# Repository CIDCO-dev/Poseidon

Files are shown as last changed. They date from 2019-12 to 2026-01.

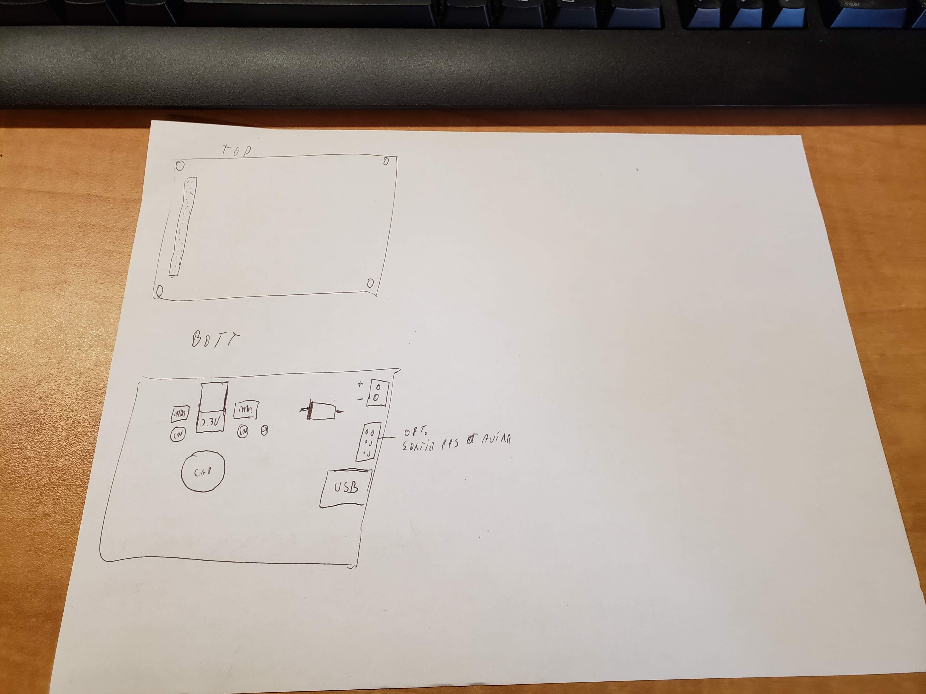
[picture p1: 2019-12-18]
docs/Devices/GPS/Hemisphere P320/20191210_094404.jpg

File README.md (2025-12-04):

# Poseidon
Hydrographic surveying platform operating system (ROS Noetic).

## Getting started (RPi4, Ubuntu 20.04, ROS Noetic)
- Clone under `/opt`: `sudo chown $USER:$USER /opt && cd /opt && git clone --recursive <repo>`
- Install: run `install/rpi4-noetic.sh` (RPi4 target).
- Build: `cd /opt/Poseidon/src/workspace && catkin_make -j1 -DCATKIN_BLACKLIST_PACKAGES="mavros;inertial_sense;velodyne;ins_piksi;velodyne_pointcloud;velodyne_driver;velodyne_laserscan;gnss_mosaic_x5;tf"`
- Source: `source /opt/ros/noetic/setup.bash` then `source /opt/Poseidon/src/workspace/devel/setup.bash`.
- Launch simulator: `roslaunch launch/Simulator/dummy_simulator_virtual-machine.launch`, then open the web UI at `http://localhost`.

## Docs
Full documentation lives in `doc/` (Markdown):
- `doc/README.md`: overview, build, run, tests
- `doc/install.md`: installation with dependencies (RPi4, Ubuntu 20.04, ROS Noetic)
- `doc/nodes.md`: list of ROS nodes
- `doc/web.md`: list of web UI pages
- `doc/web/*.md`: per-page details (index, status, diagnostics, data, map, settings, calibration, goal)
- `doc/nodes/*.md`: per-node details with inputs/outputs/params

## Tests
- C++/Python/ROS: `catkin_make run_tests -j1 -DCATKIN_BLACKLIST_PACKAGES="ins_piksi;libmavconn;echoboat_odometry;mavros_msgs;mavros;mavros_extras;test_mavros;gnss_mosaic_x5;imu_bno055;sonar_imagenex852;inertial_sense;raspberrypi_vitals;imu_null;sonar_dummy;gnss_dummy;lidar_filtering"`
- JS: `cd www/webroot/js && npm test --coverage`

## Tools
- Rosbag replay: `roslaunch launch/Echoboat/rosbag_replay.launch bag_filename:=rosbag.bag`
- Lidar georef: `./devel/lib/logger/lidarGeoreferencer -h` (supports filtering options)
- Logging modes: 1=Always ON, 2=Manual, 3=Speed based

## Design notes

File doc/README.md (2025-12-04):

# Poseidon Documentation

## Overview
- ROS Noetic hydrographic platform.
- Catkin workspace: `src/workspace`.
- Web UI: `www/webroot`.
- Install scripts: `install/stages/`.

## Prerequisites
- Ubuntu 20.04 with ROS Noetic (`/opt/ros/noetic`).
- Build tools: gcc/g++, cmake, ccache, python3, pip, rosdep.
- Node.js 18+ for JS tests (CI uses `actions/setup-node@v4`).

## Installation (RPi4, Ubuntu 20.04, ROS Noetic)
```bash
sudo chown $USER:$USER /opt
cd /opt
git clone --recursive <repo>
sh /opt/Poseidon/install/rpi4-noetic.sh
echo "source /opt/ros/noetic/setup.bash" >> ~/.bashrc
echo "source /opt/Poseidon/src/workspace/devel/setup.bash" >> ~/.bashrc
```

## Build
```bash
cd /opt/Poseidon/src/workspace
catkin_make -j1 -DCATKIN_BLACKLIST_PACKAGES="mavros;inertial_sense;velodyne;ins_piksi;velodyne_pointcloud;velodyne_driver;velodyne_laserscan;gnss_mosaic_x5;tf"
source devel/setup.bash
```

## Run (Simulator)
```bash
roslaunch launch/Simulator/dummy_simulator_virtual-machine.launch
```
Open the web UI at `http://localhost`.

## Tests
- ROS/C++: `catkin_make run_tests -j1 -DCATKIN_BLACKLIST_PACKAGES="ins_piksi;libmavconn;echoboat_odometry;mavros_msgs;mavros;mavros_extras;test_mavros;gnss_mosaic_x5;imu_bno055;sonar_imagenex852;inertial_sense;raspberrypi_vitals;imu_null;sonar_dummy;gnss_dummy;lidar_filtering"`
- JS: `cd www/webroot/js && npm test --coverage`
- Coverage summary: produced in CI (C++/Python/JS).

## Tools & Operations
- Rosbag replay: `roslaunch launch/Echoboat/rosbag_replay.launch bag_filename:=rosbag.bag`
- Lidar georef: `./devel/lib/logger/lidarGeoreferencer -h` (supports filtering with `-f -a -b -d -e`)
- Logging modes: 1=Always ON, 2=Manual, 3=Speed based

## Structure
- `src/workspace/src/<package>`: ROS packages
- `src/workspace/launch/`: launch files
- `www/webroot`: web UI assets and JS
- `install/stages`: install scripts
- `config.txt`: runtime config (no real secrets)
- Docs index: [`doc/nodes.md`](nodes.md) for ROS nodes, [`doc/web.md`](web.md) for web pages

## Notes
- Keep docs up to date here; CI can generate PDFs later if needed.
- For embedded targets, adjust blacklist/launch files for resources.

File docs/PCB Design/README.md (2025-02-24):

# Poseidon-PCB
PCBs for Poseidon Project

PCBs are design with Kicad 8.0

HB-HAT
HydroB HAT interface between RPI and devices

HB-BP
Power module bypass for Hydroblock

HB-PM
Power module for Hydroball

HB-HL
Led and hall interface module for Hydroball

HB-LED
Led PCB

HB-PM-Prog
Power Module Programmation Interface

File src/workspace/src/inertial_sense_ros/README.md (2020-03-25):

# inertial_sense

A ROS wrapper for the InertialSense uINS3 RTK-GPS-INS and Dual GPS (GPS Compassing) sensor.

## NOTICE:

To use this node, the uINS should be updated with the latest firmware found on the Inertial Sense [release page](https://github.com/inertialsense/InertialSenseSDK/releases). Download the appropriate `.hex` file and use the `firmware_update` ROS service to update the firmware
``` 
rosservice call /firmware_update ~/Download/IS_uINS-3_<...>.hex
```

## Installation
This ROS package, uses the InertialSenseSDK as a submodule. Clone this package into the catkin workspace `src` folder, then pull the submodule.

``` bash
mkdir -p catkin_ws/src
cd catkin_ws/src
catkin_init_workspace
git clone https://github.com/inertialsense/inertial_sense_ros
cd inertial_sense_ros
git submodule update --init --recursive
cd ../..
catkin_make
```

## Running the Node

```bash
rosrun inertial_sense inertial_sense_node
```

The user must be a member of the `dailout` group, or the user won't have access to the serial port.

For instructions on changing parameter values and topic remapping from the command line while using `rosrun` refer to the [Remapping Arguments](http://wiki.ros.org/Remapping%20Arguments) page. To set vector parameters, use the following syntax:

``` bash
rosparam set /inertial_sense_node/GPS_ref_lla "[40.25, -111.67, 1556.59]"
rosrun inertial_sense inertial_sense_node
```

To set parameters and topic remappings from a launch file, refer to the [Roslaunch for Larger Projects](http://wiki.ros.org/roslaunch/Tutorials/Roslaunch%20tips%20for%20larger%20projects) page, or the sample `launch/test.launch` file in this repository.

## Time Stamps

If GPS is available, all header timestamps are calculated with respect to the GPS clock but are translated into UNIX time to be consistent with the other topics in a ROS network.  If GPS is unvailable, then a constant offset between uINS time and system time is estimated during operation  and is applied to IMU and INS message timestamps as they arrive.  There is often a small drift in these timestamps (on the order of a microsecond per second), due to variance in measurement streams and difference between uINS and system clocks, however this is more accurate than stamping the measurements with ROS time as they arrive.  

In an ideal setting, there should be no jump in timestamps when GPS is first acquired, because the timestamps should be identical, however, due to inaccuracies in system time, there will likely be a small jump in message timestamps after the first GPS fix.

## Topics

Topics are enabled and disabled using parameters.  By default, only the `ins` topic is published to save processor time in serializing unecessary messages.
- `ins`(nav_msgs/Odometry)
    - full 12-DOF measurements from onboard estimator (pose portion is from inertial to body, twist portion is in body frame)
- `imu`(sensor_msgs/Imu)
    - Raw Imu measurements from IMU1 (NED frame)
- `gps`(inertial_sense/GPS)
    - unfiltered GPS measurements from onboard GPS unit
- `gps/info`(inertial_sense/GPSInfo)
    - sattelite information and carrier noise ratio array for each sattelite
- `mag` (sensor_msgs/MagneticField)
    - Raw magnetic field measurement from magnetometer 1
- `baro` (sensor_msgs/FluidPressure)
    - Raw barometer measurements in kPa
- `preint_imu` (inertial_sense/DThetaVel)
    - preintegrated coning and sculling integrals of IMU measurements
- `RTK/info` (inertial_sense/RTKInfo)
    - information about RTK status
- `RTK/rel` (inertial_sense/RTKRel)
    * Relative measurement between RTK base and rover
- `gps/obs` (inertial_sense/GNSSObservation)
    * Raw satellite observation (psuedorange and carrier phase)
- `gps/eph` (inertial_sense/GNSSEphemeris)
    * Satellite Ephemeris for GPS and Galileo GNSS constellations
- `gps/geph`
    * Satellite Ephemeris for Glonass GNSS constellation

## Parameters

* `~port` (string, default: "/dev/ttyUSB0")
  - Serial port to connect to
* `~baudrate` (int, default: 921600)
  - baudrate of serial communication
* `~frame_id` (string, default "body")
  - frame id of all measurements
* `~LTCF` (int, default: 0)
  - Local Tangent Coordinate Frame: 0 - NED, 1 - ENU

**Topic Configuration**
* `~navigation_dt_ms` (int, default: Value retrieved from device flash configuration)
   - milliseconds between internal navigation filter updates (min=2ms/500Hz).  This is also determines the rate at which the topics are published.
* `~stream_INS` (bool, default: true)
   - Flag to stream navigation solution or not
* `~stream_IMU` (bool, default: false)
   - Flag to stream IMU measurements or not
* `~stream_baro` (bool, default: false)
   - Flag to stream baro or not
* `~stream_mag` (bool, default: false)
   - Flag to stream magnetometer or not
* `~stream_preint_IMU` (bool, default: false)
   - Flag to stream preintegrated IMU or not
* `~stream_GPS`(bool, default: false)
   - Flag to stream GPS
* `~stream_GPS_info`(bool, default: false)
   - Flag to stream GPS info messages
- `~stream_GPS_raw` (bool, default: false)
   - Flag to stream GPS raw messages
- `~publishTf`(bool, default: true)
   - Flag to publish Tf transformations 'ins' to 'body_link'

**RTK Configuration**
* `~RTK_rover` (bool, default: false)
  - Enables RTK rover mode (requires base corrections from an RTK base)
* `~RTK_base` (bool, default: false)
  - Makes the connected uINS a RTK base station and enables the publishing of corrections
* `~dual_GNSS` (bool, default: false)
  - Uses both GPS antennas in a dual-GNSS configuration
* `~RTK_server_IP` (string, default: 127.0.0.1)
  - If operating as base, attempts to create a TCP port on this IP for base corrections, if rover, connects to this IP for corrections.
* `~RTK_server_port` (int, default: 7777)
  - If operating as base, creates a TCP connection at this port for base corrections, if rover, connects to this port for corrections.
* `~RTK_correction_type` (string, default: UBLOX)
  - If operating with limited bandwidth, choose RTCM3 for a lower bandwidth, but less accurate base corrections,  rover and base must match

**Sensor Configuration**
* `~INS_rpy_radians` (vector(3), default: {0, 0, 0})
    - The roll, pitch, yaw rotation from the INS frame to the output frame
* `~INS_xyz` (vector(3), default: {0, 0, 0})
    - The NED translation vector between the INS frame and the output frame (wrt output frame)
* `~GPS_ant1_xyz` (vector(3), default: {0, 0, 0})
    - The NED translation vector between the INS frame and the GPS 1 antenna (wrt INS frame)
* `~GPS_ant2_xyz` (vector(3), default: {0, 0, 0})
    - The NED translation vector between the INS frame and the GPS 2 antenna (wrt INS frame)
* `~GPS_ref_lla` (vector(3), default: {0, 0, 0})
    - The Reference longitude, latitude and altitude for NED calculation in degrees, degrees and meters (use the `set_refLLA` service to update this automatically)
* `~inclination` (float, default: 1.14878541071)
    - The inclination of earth's magnetic field (radians)
* `~declination` (float, default: 0.20007290992)
    - The declination of earth's magnetic field (radians)
* `~dynamic_model` (int, default: 8)
    - Dynamic model used in internal filter of uINS.
       - 0 = portable
       - 2 = stationary
       - 3 = pedestrian
       - 4 = automotive
       - 5 = sea
       - 6 = airborne 1G
       - 7 = airborne 2G
       - 8 = airborne 4G
       - 9 = wrist

**ASCII Output Configuration**
* `~ser1_baud_rate` (int, default: 921600)
    - baud rate for serial1 port used for external NMEA messaging (located on H6-5) [serial port hardware connections](http://docs.inertialsense.com/user-manual/Setup_Integration/hardware_integration/#pin-definition)
* `~NMEA_rate` (int, default: 0)
    - Rate to publish NMEA messages
* `~NMEA_configuration` (int, default: 0x00)
    - bitmask to enable NMEA messages (bitwise OR to enable multiple message streams).
      - GPGGA = 0x01
      - GPGLL = 0x02
      - GPGSA = 0x04
      - GPRMC = 0x08
* `~NMEA_ports` (int, default: 0x00)
    - bitmask to enable NMEA message on serial ports (bitwise OR to enable both ports) 
      - Ser0 (USB/H4-4)  = 0x01 
      - Ser1 (H6-5) = 0x02 

## Services
- `single_axis_mag_cal` (std_srvs/Trigger)
  - Put INS into single axis magnetometer calibration mode.  This is typically used if the uINS is rigidly mounted to a heavy vehicle that will not undergo large roll or pitch motions, such as a car. After this call, the uINS must perform a single orbit around one axis (i.g. drive in a circle) to calibrate the magnetometer [more info](http://docs.inertialsense.com/user-manual/Setup_Integration/magnetometer_calibration/)
- `multi_axis_mag_cal` (std_srvs/Trigger)
  - Put INS into multi axis magnetometer calibration mode.  This is typically used if the uINS is not mounted to a vehicle, or a lightweight vehicle such as a drone.  Simply rotate the uINS around all axes until the light on the uINS turns blue [more info](http://docs.inertialsense.com/user-manual/Setup_Integration/magnetometer_calibration/)
- `firmware_update` (inertial_sense/FirmwareUpdate)
  - Updates firmware to the `.hex` file supplied (use absolute filenames)
* `set_refLLA_current` (std_srvs/Trigger)
  - Takes the current estimated position and sets it as the `refLLA`.  Use this to set a base position after a survey, or to zero out the `ins` topic.1
* `set_refLLA_value` (std_srvs/Trigger)
  - Sets `refLLA` to the values passed as service arguments of type float64[3].  Use this to set refLLA to a known value.

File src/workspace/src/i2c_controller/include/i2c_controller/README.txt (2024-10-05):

action to perform :
led_error
led_ready
led_recording
led_warning
led_nofix
get_led_state
gps_fix_ready
gps_fix_recording
get_humidity
get_temperature
get_voltage
get_shuntVoltage
get_batteryTemperature

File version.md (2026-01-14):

# Version History (English)

## 2026-01-12
- CI: clean Catkin build/devel/logs on self-hosted runners before builds to avoid `.built_by` permission errors.
- CI: pre-clean the GitHub Actions workspace with sudo before checkout to avoid permission errors during repository cleanup.

## 2026-01-08
- e2e: require root launch by default (`POSEIDON_E2E_LAUNCH_AS_ROOT=1`) and reuse the already-started service during the E2E run to avoid duplicate roslaunch.
- diagnostics/e2e: honor `POSEIDON_E2E_LAUNCH_AS_ROOT=1` when the websocket integration test launches `launchROSService.sh`.
- e2e: split the E2E runner into explicit phases (start ROS + wait for nodes, backend test, UI test) with optional required node gating (`POSEIDON_E2E_REQUIRED_NODES`).
- CI: set `POSEIDON_E2E_LAUNCH_AS_ROOT=1` for hardware E2E runs to ensure sensor access.

## 2025-12-18
- e2e: added Playwright-based headless UI smoke test (verifies `diagnostics.html` populates diagnostics + running nodes tables and required sensor diagnostics report OK; optional telemetry check on `index.html`).
- e2e: added unified runner script that starts Poseidon, serves `www/webroot`, waits for ports, runs backend websocket E2E + UI headless checks, and stores artifacts under `test/e2e/artifacts`.
- diagnostics/e2e: gated the launchROSService websocket test behind `POSEIDON_E2E=1` and added `POSEIDON_E2E_REUSE_RUNNING=1` to support CI benches that already run ROS.
- diagnostics: start the WebSocket server from inside the asyncio loop to be compatible with newer `websockets` versions (fixes port 9099 not opening on some systems).
- launch: made `launchROSService.sh` relocatable via `POSEIDON_ROOT` (no longer hard-coded to `/opt/Poseidon`).
- launch: avoid `set -u` in `launchROSService.sh` so sourcing `/opt/ros/noetic/setup.bash` does not fail when ROS scripts reference unset variables (fixes CI E2E startup).
- launch/e2e: pass `loggerPath` and `configPath` from `POSEIDON_LOGGER_PATH` / `POSEIDON_CONFIG_PATH` via `launchROSService.sh` (avoids invalid nested `$(optenv ...)` substitutions in roslaunch args).
- CI: added optional "hardware E2E" workflow steps (Playwright install, run E2E, upload artifacts) triggered on `workflow_dispatch` or pushes to `main/master`.
- diagnostics/e2e: make IMU/sonar communication thresholds configurable via env vars (`POSEIDON_DIAG_IMU_*`, `POSEIDON_DIAG_SONAR_*`) to reduce false negatives on slower benches.
- e2e: allow tuning diagnostics refresh polling delay via `POSEIDON_E2E_DIAGNOSTICS_REFRESH_DELAY_MS` for longer-running diagnostics windows.
- e2e: on UI failure, runner now dumps `roslaunch` tail + basic `rostopic`/diagnostics websocket debug into the job logs for faster triage.
- e2e: avoid `set -u` in the E2E runner when sourcing ROS setup scripts (prevents `ROS_DISTRO: unbound variable` on some environments).
- e2e: keep a DBT NMEA writer running for the whole E2E so `/depth` can be validated when `DIAGNOSTICS_FAKE_SERIAL_PORT` is available.
- e2e: optional exclusive mode (`POSEIDON_E2E_EXCLUSIVE=1`) stops the system `ros` service and frees websocket ports before starting Poseidon to avoid port conflicts on benches.
- launch: pass `sonarDevice` into the Hydrobox launch and map it to `/Sonar/device` so the sonar node can be pointed at a test serial adapter.

## 2025-12-03
- diagnostics: added end-to-end nosetest that launches `launchROSService.sh`, waits for the 9099 diagnostics websocket, sends `updateDiagnostic`, and validates the returned payload; optional DBT feed on `DIAGNOSTICS_FAKE_SERIAL_PORT` (default `/dev/ttyUSB1`) to drive sonar without touching `/dev/sonar`.
- diagnostics: declare `python3-websockets` as exec/test dependency so websocket clients/servers are available during integration runs.
- diagnostics: fixed indentation in the launchROSService websocket test teardown to avoid SyntaxErrors during nosetests.
- diagnostics: guarded `asyncio.set_event_loop` in `diagnostics_websocket.start_server` to prevent dummy-loop `AssertionError` in unit tests.

## 2025-12-02
- Web UI: System Status now shows wlan0 state + SSID using sysfs/proc+iwgetid (no nmcli dependency in telemetry path).
- hydroball_data_websocket: publish Wi‑Fi status/SSID in telemetry payload (`telemetry.wifi`), sourced from `/sys/class/net/wlan0/operstate` and `/proc/net/wireless`.
- wifi_file_transfer_config: remove legacy C++ backups; node now purges old Wi‑Fi connections on config change and documentation/comments converted to English.
- wifi_file_transfer_config: added Python unit tests for wifi_config_node (helpers, nmconnection parsing, autoconnect parsing, purge logic, configuration callback) wired via catkin nosetests.
- Launch: replace missing `diagnostics_node` with `diagnostics_websocket.py` in Hydrobox/Hydroball/Simulator launch files to fix diagnostics startup errors.
- diagnostics: add package-path fallback so diagnostics_websocket imports sibling diagnostic modules when run from install space (fix ModuleNotFoundError on diagnostics_test_base).
- diagnostics: fix `getRunningNodes` handler to unpack publisher/subscriber/service lists correctly (no more "too many values to unpack").
- diagnostics: add DNS resolution check (`google.com`) and Internet connectivity check (`http://example.com`) to the diagnostics suite.
- diagnostics: run Internet connectivity first and skip DNS/API checks when connectivity fails to reduce noisy errors.
- diagnostics: API connection test now uses a configurable timeout (default 2s) to avoid hanging when the API domain is blocked.
- diagnostics: added unit tests for the diagnostics websocket node (commands, node listing, lifecycle helpers) to cover its behaviors without ROS master dependencies.
- diagnostics: install the websocket integration test into the package bin path and skip cleanly when the `websockets` module is missing, so rostest can locate/execute it without false negatives.
- install: rewrote `install/stages/ethernet_move_hotspot_rpi4.sh` with Unix line endings so the bash shebang runs without `/bin/bash^M` errors.
- install: fixed `ethernet_move_hotspot_rpi4.sh` variable handling (no more escaped `$`/awk errors) and robust interface-name replacement in Hotspot.nmconnection.
- launch: All Hydrobox profiles now start `wifi_file_transfer_config_node` so Wi‑Fi provisioning is consistent across RPi/Rock and simulator setups.
- launch: Fixed wifi file transfer node type to `wifi_config_node.py` in all launch profiles/simulator so roslaunch can locate the installed Python node.
- wifi_file_transfer_config: protect hotspot/non-target interfaces (e.g., wlan1) and force new connections onto `wlan0`; skip deleting hotspot profiles when applying Wi‑Fi config.
- wifi_file_transfer_config: refuse to apply Wi‑Fi changes if the hotspot interface (default wlan1) is missing and guard against running when the target interface is absent.
- hydroball_data_websocket: use nmcli to populate Wi‑Fi SSID/state, drop iwgetid dependency, and clear SSID when disconnected.
- Web UI (status): Wi‑Fi row matches other bars (full-width gradient green/red) with SSID + state inline in the header; bar color now follows `wifi.state` up/down.
- Tests: update statusScript Jest stubs to support `.css()` chaining after Wi‑Fi bar changes.

## 2025-12-01
- diagnostics: added rostest that launches the WebSocket node and validates `updateDiagnostic` response payload (catkin test friendly).
- raspberrypi_vitals: declare logger_service and power_management_msg dependencies so ToggleLogging and battery message headers exist at build time.
- diagnostics: install the websocket integration test script via catkin so rostest can locate/execute it.
- ROS tests: add pytest skip guards for ROS-dependent Python tests to avoid failures when ROS Python modules are absent.

## 2025-11-27
- CI: gcovr step split into separate XML/HTML runs (no more skipped HTML output) and coverage summary script now falls back to lcov/HTML when XML is absent.
- CI: coverage summary now also falls back to JS lcov when coverage-summary.json is missing (ensures JS coverage is reported).
- CI: coverage summary surfaces JUnit test totals/errors/failures and lists failing suites (links to junit-test-results artifact).
- JS: VM-based Jest tests now instrument scripts before execution so coverage is reported correctly (no longer 0%).
- raspberrypi_vitals: ensure targets depend on generated messages (catkin_EXPORTED_TARGETS) and declare i2c_controller_service in CATKIN_DEPENDS to fix missing `raspberrypi_vitals_msg/sysinfo.h` during build.
- gnss_zed_f9p: declare binary_stream_msg/virtual_serial_port deps and depend on catkin_EXPORTED_TARGETS so generated headers (e.g., Stream.h) exist before building.
- lidar_filtering: fixed tests by passing min/max angle/distance as const refs in Filters helpers (no more rvalue binding errors).
- CI: junit summary lines are now highlighted in red when errors/failures/skipped are non-zero for easier scanning.
- Docs: agent guidance updated to keep Markdown docs in `doc/` (source of truth) with CI able to generate PDFs for download.
- Docs: README and doc/README now target RPi4 on Ubuntu 20.04, using install/rpi4-noetic.sh as the install path.
- Docs: added `doc/install.md` detailing prerequisites and install steps for RPi4 Ubuntu 20.04.
- Docs: added `doc/nodes.md` (ROS nodes list) and `doc/web.md` (web UI pages list); README links updated.
- Docs: added per-web-page stubs in `doc/web/*.md` (index, status, diagnostics, data, map, settings, calibration, goal).
- Docs: node/web index now link to specific Markdown docs and source files for easier navigation.
- Docs: documented `sonar_dummy_node` (overview, published topic, config service keys, behavior).
- Docs: documented `raspberrypi_vitals_node` (vitals topic fields, I2C service calls, thresholds).
- Docs: documented `imu_null_node` (zeroed IMU publisher at 200 Hz).
- Docs: documented `hydroball_config_websocket_node` (websocket config server, services, config file handling, IMU transform broadcast).
- Docs: documented `logger_binary_node` (binary logging of GNSS/IMU/sonar/lidar/vitals/speed, rotation/transfer).
- Docs: documented `logger_text_node` (per-stream text logs, rotation/transfer).
- Docs: documented `gnss_dummy_node` (synthetic NavSatFix publisher with alternating status/path).
- Docs: documented `gnss_zed_f9p_node` (serial UBX ingest, speed/diag/raw stream).
- Docs: documented `video_recorder_node` (camera capture → EXIF-tagged PNGs with interpolated GNSS).
- Docs: documented `hydroball_data_websocket_node` (WebSocket telemetry/recording control on port 9002).
- Docs: documented `state_controller_node` (aggregates fix/IMU/depth/vitals into state + get_state service).
- Docs: documented `sonar_nmea_0183_tcp_client` (network + serial NMEA readers publishing depth/fix/speed).
- Docs: documented `diagnostics_websocket_node` (WebSocket diagnostics/ running-nodes commands on port 9099).
- Docs: documented `imu_dummy_node` (synthetic IMU on imu/data at 200 Hz).
- Docs: documented `gnss_mosaic_x5_node` (raw SBF logger; waits for fix, reads serial, writes .sbf).
- Docs: documented `lidar_filtering_node` (angle/distance pointcloud filter).
- Docs: documented `hydroball_files_websocket_node` (WebSocket file listing/deletion/transfer control on port 9003).

# 2025-12-02
- Diagnostics: added unit tests for the diagnostics websocket node (commands, node listing, lifecycle helpers) to cover its behaviors without ROS master dependencies.

## 2025-11-27

## 2025-11-26
- Install scripts: added shared chrony update script (PPS/NMEA + pool.ntp.org); lighttpd now points to `/opt/Poseidon/www/webroot`.
- Logger: removed warning spam when toggle requested without GPS fix (ROS1).
- CI: GitHub Actions now posts C++/Python/JS coverage summary to the workflow summary.
- Logger: transfer loop now counts zip files once, reports status, sends, and removes on success; RapidJSON string creation simplified.
- CI: Fixed YAML indentation for coverage summary step (workflow now parses correctly).
- CI: Coverage summary heredoc anchored with indentation (python block).
- CI: Coverage summary heredoc flattened (no leading spaces) to avoid Python IndentationError.
- CI: Coverage summary now runs from a separate script `.github/workflows/scripts/coverage_summary.py`.
- Build fix: added `binary_stream_msg` dependency to diagnostics package (resolves missing `binary_stream_msg/Stream.h` include).

## 2025-11-25
- Added HTTPS transfer integration tests for logger binary and text nodes (local TLS server, payload verification).
- Added memory-resilience tests: repeated failed transfers must not increase RSS.
- Fixed `create_json_str` to avoid allocation leak (use `SetString` without manual `new`).
- Updated agent guidelines to maintain this `version.md`.
- Updated agent guidelines: C++ formatting/lint (`clang-format`, `clang-tidy`) now tracked in the Review & PR checklist.
- Updated agent guidelines: Python formatting (`black`) added to the Review & PR checklist.
- CI: JavaScript tests step now targets `www/webroot/js` (npm ci/install + npm test if package.json present).
- Added Jest setup in `www/webroot/js` with a syntax smoke test for all JS files.
- Added Jest tests for dashboardscript.js and script.js (basic DOM/jQuery stubs, helper behavior checks).
- Added Jest test stub for poseidon.js (verifies WebSocketInit is defined).
- Added Jest tests for statusScript.js (processState handling of uptime/humidity and missing telemetry).
- Added Jest tests for settingsScript.js (rendering config and saveConfig payload).
- Added Jest tests for recordingScript.js and mapScript.js (stubs for WebSocket/Leaflet; basic behavior checks).
- Added Jest tests for diagnosticsScript.js (table population for diagnostics and running nodes).
- Added Jest tests for dataScript.js (state processing, publish status UI updates).
- Added Jest test for calibrationScript.js (zeroImu command dispatch).
- JavaScript: npm test now runs Jest with coverage (collects coverage excluding minified/vendor).
- Fixed logger text test build by defining `currentRssBytes` helper in `test_logger_text_node.cpp`.
- CI: add C++ coverage via gcovr, Python coverage via coverage/pytest, JS coverage artifact upload; switched C++ build to `--coverage`.
- CI: install Node 18 with setup-node to satisfy Jest engine requirements for JS tests.
- JS: add guards/stubs for WebSocket/jQuery/Leaflet in browser scripts to allow Jest to run headless, and exclude node_modules/coverage from syntax scan.
- JS: added Jest jsdom setup with global stubs (window/document/$/WebSocket), guarded polling, and map/WKT fallbacks to stabilize headless tests and avoid npm ci lockfile errors.
- JS tests: added explicit `jest-environment-jsdom` devDependency to satisfy Jest config.
- JS housekeeping: generated package-lock for reproducible installs and removed committed coverage output; keep coverage artifacts untracked.
- hydroball_config_websocket: add message deps (geometry/state/setting) to catkin/package.xml and enforce build order on message targets to fix missing Setting.h during catkin_make.
- Logger tests: removed embedded PEM key/cert; tests now generate ephemeral self-signed TLS material at runtime to avoid shipping secrets.
- sonar_nmea_0183_tcp_client: use ROS params for IP/port (instead of argv) and add socket receive timeout to reconnect if the network stream stalls.
- Install scripts: added shared chrony update script (PPS/NMEA + pool.ntp.org); lighttpd now points to `/opt/Poseidon/www/webroot`.

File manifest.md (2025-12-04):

# Poseidon — Project Manifest

This document summarizes Poseidon: goals, architecture, dependencies, install/build/run procedures, key launch profiles, and core ROS nodes and topics.

## Overview
- Platform: ROS Noetic (Ubuntu 20.04), Catkin workspace.
- Purpose: Embedded OS for hydrographic surveying (GNSS, IMU, sonar, lidar, power management, logging, on‑device web UI).
- License: MIT (see `LICENSE`).

## Top‑Level Layout
- `src/workspace`: Catkin workspace
  - `src`: ROS packages (C++/Python): `logger`, `gnss_zed_f9p`, `imu_bno055`, `sonar_*`, `state_controller`, `hydroball_*_websocket`, `power_*`, etc.
  - `launch`: `roslaunch` files (Echoboat, Hydrobox, Hydroball, Simulator, Cartographer, Rosbag, Binairy)
  - `config`: workspace‑specific config
- `install`: install/provision scripts (stages for x64, RPi, RockPi)
- `tools`: utilities (rosbag editing, lidar georeferencing, GNSS config, I2C tools)
- `www/webroot`: static web UI (dashboard, data, settings, map)
- `service`: system scripts (e.g., `uart_on_boot.sh`)
- `georef`: Python library for geodesy/ENU + tests
- `README.md`: install/build/run (VM and simulation)
- `Jenkinsfile`: CI pipeline (unit tests on ROS VM)

## Launch Entry Points
- WebSockets only: `roslaunch launch/websocket.launch`
- VM simulator: `roslaunch launch/Simulator/dummy_simulator_virtual-machine.launch`
- Echoboat (example): `roslaunch launch/Echoboat/echoboat.launch`
- Hydrobox (RPi, NMEA sonar + ZED‑F9P + BNO055): `roslaunch launch/Hydrobox/hydrobox_rpi_nmeadevice_ZED-F9P_bno055.launch`
- GNSS helpers: scripts `bin_mosaic-x5.sh`, `bin_piksi.sh`

`launchROSService.sh` centralizes common launch profiles and is used by the systemd `ros` service.

## Configurations & Features

### Common Features
- GNSS via gpsd + vendor node: publishes `fix`, `speed`, `gnss_status`, optional binary stream; `.ubx` logging supported.
- IMU BNO055 (I2C) with calibration: publishes `/imu/data`, `/imu/raw`, `/imu/mag`, `/imu/temp`.
- Sonar depth acquisition (NMEA 0183 device or Imagenex 852): publishes `depth` (and `depth_enu` where applicable).
- I2C board and LED/status handling: `i2c_controller`.
- System vitals: `raspberrypi_vitals` (CPU temp/load, RAM/HDD, uptime, battery voltage).
- State aggregation: `state_controller` combines GNSS/IMU/sonar/vitals into `state`.
- Logging: `logger_text_node` with file rotation, modes (Always/Manual/Speed), geofence and optional API transfer.
- WebSockets/UI: `hydroball_config_websocket`, `hydroball_data_websocket`, `hydroball_files_websocket`.
- Diagnostics: `diagnostics` WebSocket diagnostics and communication checks.
- Shared launch args: `loggerPath`, `configPath`, `gpsdIp`, `gpsdPort`.

### Hydrobox‑Specific
- Multiple hardware and GNSS variants: RPi and Rock profiles; GNSS receivers include Piksi and Mosaic X5 in addition to ZED‑F9P (see `launch/Hydrobox/*`).
- Optional “IMU null” profiles (no IMU).
- Imagenex 852 Python driver variant in some profiles (no trigger control).
- Optional rosbag record of all topics in certain profiles.

### Hydroball‑Specific
- Power control and safe shutdown: `power_control` for rails, `power_management` triggers graceful shutdown on low voltage.
- Imagenex 852 C++ driver with trigger control: `trigger_mode` (auto|manual), `manual_ping_rate`, `data_points`.
- Alternate sonar ISA500 via NMEA device (`nmea_device_node`).
- Explicit sonar datagram extension `.img852` configured in logger params.

## Build
Prereqs (excerpt):
- ROS Noetic, catkin, g++, python3-rosdep, ros-noetic-tf2-geometry-msgs, ros-noetic-mavros, ros-noetic-sbg-driver
- Tools: `python3-wstool`, `python3-rosinstall`, `build-essential`, `ninja-build` (for Cartographer), `gpsd` and `gpsd-clients` (x64)

Steps (VM, per `README.md`):
1) Clone into `/opt`: `/opt/Poseidon`
2) Run install scripts for your target, e.g.: `install/stages/1-base-ros-noetic.sh`, `2-x64.sh`, `3-network.sh`, `4-x64.sh`, `5-finalize.sh`
3) Source ROS: `source /opt/ros/noetic/setup.bash`
4) Build workspace: `cd src/workspace && catkin_make -j1 -DCATKIN_BLACKLIST_PACKAGES="mavros;...;inertial_sense;lidar_filtering"`
5) Source workspace: `source devel/setup.bash`

Notes:
- The workspace toplevel `CMakeLists.txt` is a symlink to Catkin’s `toplevel.cmake`.
- Embedded targets may use a blacklist to reduce footprint.

## Run
- Simulator: `roslaunch launch/Simulator/dummy_simulator_virtual-machine.launch`
- Production: choose a profile under `launch/Hydrobox/*` or `launch/Echoboat/*`, or enable the systemd `ros` service (see `install/stages/4-x64.sh`).
- Web UI: served from `www/webroot` (see VM network scripts). Open `http://localhost`.

## Application Configuration
- File: `config.txt` at repo root. Common keys:
  - `apiKey`, `apiServer`, `apiPort`, `apiUrlPath`
  - `geofence` (WKT), sensor offsets (`headingOffset`, `pitchOffset`, `rollOffset`)
  - Sonar: `sonarAbsorbtion`, `sonarPulseLength`, `sonarRange`, `sonarSerialBaudRate`, `sonarStartGain`
  - Logging: `logRotationIntervalSeconds`, `loggingMode` (1=Always ON, 2=Manual, 3=Speed based)
  - Network: `wifiSSID`, `wifiPassword`, `wifiTransferEnabled`

Launch files commonly pass `configPath` and `loggerPath` to WebSocket/logger nodes.

## System Service (systemd)
- Service `ros` created by `install/stages/4-x64.sh` with `ExecStart=/opt/Poseidon/launchROSService.sh`.
- Dependencies: `gpsd.service`, `hwrtc.service` (if present)
- Control: `sudo systemctl enable|start|stop ros`

## Tests and CI
- Unit tests: `catkin_make run_tests -j1` (see README blacklist examples).
- Jenkins: `Jenkinsfile` runs `scripts/vm_tests` and collects `build/test_results/angles/gtest-utest.xml`.

## Useful Scripts (examples)
- Rosbag record/replay: `tools/ROSBag-Eample/*.sh`, `launch/Rosbag/*`
- Lidar georeferencing: `tools/Georef_script/*.bash`, `logger/lidarGeoreferencer` (after build)
- Rosbag editing (python/C++): `tools/Edit-Rosbag/*`
- GNSS ZED‑F9P config/validate: `tools/GNSS-Config-Files/ZED-F9P/*`
- I2C/Diagnostics: `tools/i2c/*`, package `diagnostics`

## Web UI
- Static assets in `www/webroot` (SB Admin 2, MIT): `index.html`, `status.html`, `settings.html`, `map.html`, etc.
- WebSocket nodes (`hydroball_*_websocket`) expose configuration, data and files to the UI.
- Status page now surfaces Wi‑Fi state/SSID (wlan0) from telemetry.

## Network and Ports (common)
- Internal API: `apiPort` (8080 default in `config.txt`).
- GPSD: 2947 (default), passed via launch args.
- Web: local HTTP server; Wi‑Fi file transfer via dedicated scripts/services.

## Data and Logs
- Default recording folder: `/opt/Poseidon/www/webroot/record/` (see `loggerPath` launch arg).
- GNSS binary datagrams may use `.ubx` (see `/logger/fileExtensionForGpsDatagram`).

## Nodes and Topics
Core nodes used by main launch profiles, with their primary ROS interfaces.

- i2c_controller_node (package `i2c_controller`)
  - Publishes: `led_control` (std_msgs/String)
  - Services (server): `i2c_controller_service` (i2c_controller_service/i2c_controller_service)
  - Services (client): `get_logging_status` (logger_service)
  - Args: `boardVersion` (e.g., 2.2)

- power_management_node (package `power_management`)
  - Services (client): `i2c_controller_service` → action `get_voltage`
  - Behavior: triggers graceful shutdown via systemd if voltage is critical

- raspberrypi_vitals_node (package `raspberrypi_vitals`)
  - Publishes: `vitals` (raspberrypi_vitals_msg/sysinfo)

- hydroball_config_websocket_node (package `hydroball_config_websocket`)
  - Publishes: `configuration` (setting_msg/Setting)
  - Services (server): `get_configuration` (setting_msg/ConfigurationService), `zero_imu_offsets` (setting_msg/ImuOffsetService)
  - Args: `configPath` to `config.txt`

- gpsd_client (package `gps_umd`)
  - Publishes: `fix` (sensor_msgs/NavSatFix)
  - Args: `gpsdIp`, `gpsdPort`

- gnss_zed_f9p_node (package `gnss_zed_f9p`)
  - Subscribes: `fix` (sensor_msgs/NavSatFix)
  - Publishes: `speed` (nav_msgs/Odometry), `gnss_bin_stream` (binary_stream_msg/Stream), `gnss_status` (gnss_status_msg/GnssDiagnostic)
  - Args: `loggerPath` (output folder), `gnssPortPath` (serial device)

- gnss_mosaic_x5_node (package `gnss_mosaic_x5`)
  - Subscribes: `fix` (sensor_msgs/NavSatFix)

- sonar_nmea_0183_tcp_client (package `sonar_nmea_0183_tcp_client`)
  - Publishes: `depth` (geometry_msgs/PointStamped), `fix` (sensor_msgs/NavSatFix), `speed` (nav_msgs/Odometry)
  - Subscribes: `configuration` (setting_msg/Setting)
  - Variants: `nmea_network_node` (TCP) and `nmea_device_node` (serial)

- sonar_imagenex852 (package `sonar_imagenex852`)
  - Publishes: `depth` (geometry_msgs/PointStamped), `depth_enu` (geometry_msgs/PointStamped)
  - Subscribes: `configuration` (setting_msg/Setting)

- sonar_imagenex852_c_node (package `sonar_imagenex852_c`)
  - Publishes: `depth` (geometry_msgs/PointStamped), `depth_enu` (geometry_msgs/PointStamped), `sonar_bin_stream` (binary_stream_msg/Stream)
  - Subscribes: `configuration` (setting_msg/Setting)

- sonar_dummy_node (package `sonar_dummy`)
  - Publishes: `depth` (geometry_msgs/PointStamped)

- imu_bno055 (executable `bno055_i2c_node`, package `imu_bno055`, namespace `imu`)
  - Publishes: `/imu/data` (sensor_msgs/Imu), `/imu/raw` (sensor_msgs/Imu), `/imu/mag` (sensor_msgs/MagneticField), `/imu/temp` (sensor_msgs/Temperature), `/imu/status` (diagnostic_msgs/DiagnosticStatus)
  - Params: `device`, `address`, `frame_id`, `calibrationFile`

- imu_dummy_node (package `imu_dummy`)
  - Publishes: `imu/data` (sensor_msgs/Imu)

- state_controller_node (package `state_controller`)
  - Subscribes: `fix` (sensor_msgs/NavSatFix), `/imu/data` (sensor_msgs/Imu), `depth` (geometry_msgs/PointStamped), `vitals` (raspberrypi_vitals_msg/sysinfo)
  - Publishes: `state` (state_controller_msg/State)
  - Services (server): `get_state` (state_controller_msg/GetStateService)

- logger_text_node / logger_binary_node (package `logger`)
  - Subscribes: `fix`, `imu/data`, `depth`, `speed`, `configuration`, `velodyne_points`, `gnss_bin_stream`, `vitals`, `sonar_bin_stream`
  - Services (server): `get_logging_status`, `toggle_logging`, `get_logging_mode`, `set_logging_mode`, `trigger_transfer` (logger_service)
  - Params: `/logger/fileExtensionForGpsDatagram`, `/logger/fileExtensionForSonarDatagram`
  - Args: `loggerPath` (output folder)

- diagnostics_websocket_node (package `diagnostics`)
  - Serves diagnostics over WebSocket (default port 9099)
  - Internally probes topics: `fix`, `/imu/data`, `depth`, `gnss_bin_stream` and system state

- hydroball_data_websocket_node (package `hydroball_data_websocket`)
  - Subscribes: `state` (state_controller_msg/State), `gnss_status` (gnss_status_msg/GnssDiagnostic)
  - Services (client): `get_logging_status`, `toggle_logging`, `get_logging_mode`, `set_logging_mode`
  - Emits telemetry over WebSocket (port 9002) including `telemetry.wifi` (wlan0 state/connected/ssid from sysfs/proc)
  - Args: `loggerPath` (for exposing recent logs over WS)

- hydroball_files_websocket_node (package `hydroball_files_websocket`)
  - Purpose: expose files/recordings over WebSocket (no primary ROS topics)
  - Args: `loggerPath`

- wifi_file_transfer_config_node (package `wifi_file_transfer_config`)
  - Subscribes: `configuration` (setting_msg/Setting)
  - Services (client): `get_configuration` to fetch `wifiSSID`, `wifiPassword`, `wifiTransferEnabled`
  - Behavior: purges existing Wi‑Fi profiles and recreates the configured SSID via nmcli (autoconnect toggle)

### Tests (auto-generated)

Note: Coverage percentages are intentionally omitted.

- Package `diagnostics`
  - Node `diagnostics_node` (C++) — Tests: no tests detected
  - Node `diagnostics_websocket_node` (C++) — Tests: no tests detected
- Package `echoboat_odometry`
  - Node `echoboat_odometry_node` (C++) — Tests: no tests detected
- Package `gnss_dummy`
  - Node `gnss_dummy_node` (C++) — Tests: test_gnss_dummy.cpp — Functions: GNSS::message
- Package `gnss_mosaic_x5`
  - Node `gnss_mosaic_x5_node` (C++) — Tests: gnss_mosaic_x5_test.launch, test_gnss_mosaic_x5_node.cpp — Functions: MosaicX5::run, MosaicX5::processDatagram (override), MosaicX5::openAndInitSerialPort, MosaicX5::readUntilAlignedWithDatagrams, MosaicX5::readAndProcessOneDatagram
- Package `gnss_zed_f9p`
  - Node `gnss_zed_f9p_node` (C++) — Tests: gnss_zed_f9p_test.launch, test_gnss_zed_f9p.cpp — Functions: ZEDF9P::processFrame, ZEDF9P::validateChecksum, ZEDF9P::serialRead
- Package `hydroball_config_websocket`
  - Node `hydroball_config_websocket_node` (C++) — Tests: test_hydroball_config_websocket.cpp — Functions: ConfigurationServer::run, ConfigurationServer::broadcastConfiguration, ConfigurationServer::stop
- Package `hydroball_data_websocket`
  - Node `hydroball_data_websocket_node` (C++) — Tests: hydroball_data_websocket_test.launch, test_hydroball_data_websocket.cpp — Functions: TelemetryServer::run, TelemetryServer::stop, TelemetryServer::convertState2json
- Package `hydroball_files_websocket`
  - Node `hydroball_files_websocket_node` (C++) — Tests: test_hydroball_files_websocket.cpp — Functions: ControlFiles::run, ControlFiles::sendFileList, ControlFiles::buildFileListJson, ControlFiles::stop
- Package `i2c_controller`
  - Node `i2c_controller_node` (C++) — Tests: no tests detected
- Package `imu_bno055`
  - Node `bno055_i2c_node` (C++) — Tests: imu_bno055_node.test, test_imu_bno055_node.cpp — Functions: topic publication only (no specific functions asserted)
  - Node `bno055_i2c_calibration` (C++) — Tests: imu_bno055_node.test, test_imu_bno055_node.cpp — Functions: topic publication only (no specific functions asserted)
- Package `imu_dummy`
  - Node `imu_dummy_node` (C++) — Tests: test_imu_dummy.cpp — Functions: QuaternionUtils::applyTransform, QuaternionUtils::quaternion2YPR, QuaternionUtils::modulo360, QuaternionUtils::flipHeading, QuaternionUtils::body2Enu
- Package `imu_null`
  - Node `imu_null_node` (C++) — Tests: test_imu_null.cpp — Functions: QuaternionUtils::applyTransform, QuaternionUtils::quaternion2YPR, QuaternionUtils::modulo360, QuaternionUtils::flipHeading, QuaternionUtils::body2Enu
- Package `inertial_sense_ros`
  - Node `inertial_sense_node` (C++) — Tests: test_inertialsense_node.cpp
- Package `ins_piksi`
  - Node `ins_piksi_node` (C++) — Tests: ins_piksi_test.launch, test_ins_piksi_node.cpp — Functions: Piksi::run, Piksi::readUntilAlignedWithDatagrams, Piksi::readAndProcessOneDatagram, Piksi::openAndInitSerialPort, Piksi::processDatagram (override)
- Package `lidar_filtering`
  - Node `lidar_filtering_node` (C++) — Tests: lidar_filters_tests.cpp — Functions: Filters::horizontalAngleFilter, Filters::distanceFilter
- Package `logger`
  - Node `logger_text_node` (C++) — Tests: logger_binary_node_test.launch, logger_text_node_test.launch, test_logger_binary_node.cpp, test_logger_text_node.cpp — Functions: LoggerText::finalize, LoggerText::rotate, LoggerText::gnssCallback, LoggerText::imuCallback, LoggerText::sonarCallback, LoggerText::lidarCallBack
  - Node `logger_binary_node` (C++) — Tests: logger_binary_node_test.launch, logger_text_node_test.launch, test_logger_binary_node.cpp, test_logger_text_node.cpp — Functions: LoggerBinary::finalize, LoggerBinary::rotate, LoggerBinary::gnssCallback, LoggerBinary::imuCallback, LoggerBinary::sonarCallback, LoggerBinary::lidarCallBack, PoseidonBinaryReader::read
  - Node `poseidonReader` (C++) — Tests: logger_binary_node_test.launch, logger_text_node_test.launch, test_logger_binary_node.cpp, test_logger_text_node.cpp
  - Node `lidarGeoreferencer` (C++) — Tests: logger_binary_node_test.launch, logger_text_node_test.launch, test_logger_binary_node.cpp, test_logger_text_node.cpp
  - Node `calib_printer` (C++) — Tests: logger_binary_node_test.launch, logger_text_node_test.launch, test_logger_binary_node.cpp, test_logger_text_node.cpp
  - Node `vital_printer` (C++) — Tests: logger_binary_node_test.launch, logger_text_node_test.launch, test_logger_binary_node.cpp, test_logger_text_node.cpp
- Package `power_control`
  - Node `main.py` (Python) — Tests: no tests detected
- Package `power_management`
  - Node `power_management_node` (C++) — Tests: no tests detected
- Package `raspberrypi_vitals`
  - Node `raspberrypi_vitals_node` (C++) — Tests: test_raspberrypi_vitals.cpp — Functions: topic field range checks only
- Package `sonar_dummy`
  - Node `sonar_dummy_node` (C++) — Tests: test_sonar_dummy.cpp — Functions: Sonar::message
- Package `sonar_imagenex852`
  - Node `main.py` (Python) — Tests: sonar_imagenex852_node.test, test_sonar_imagenex852_node.cpp — Functions: topic publication only (no specific functions asserted)
- Package `sonar_imagenex852_c`
  - Node `sonar_imagenex852_c_node` (C++) — Tests: sonar_imagenex852_node.test, test_sonar_imagenex852_node.cpp — Functions: topic publication only (no specific functions asserted)
- Package `sonar_nmea_0183_tcp_client`
  - Node `nmea_device_node` (C++) — Tests: sonar_nmea_0183_test.launch, test_sonar_nmea_0183_device_client.cpp — Functions: BaseNmeaClient::extractGGA, BaseNmeaClient::extractDBT, BaseNmeaClient::extractVTG, BaseNmeaClient::validateChecksum
  - Node `nmea_network_node` (C++) — Tests: sonar_nmea_0183_test.launch, test_sonar_nmea_0183_device_client.cpp — Functions: BaseNmeaClient::extractGGA, BaseNmeaClient::extractDBT, BaseNmeaClient::extractVTG, BaseNmeaClient::validateChecksum
  - Node `device_node` (C++) — Tests: sonar_nmea_0183_test.launch, test_sonar_nmea_0183_device_client.cpp — Functions: BaseNmeaClient::extractGGA, BaseNmeaClient::extractDBT, BaseNmeaClient::extractVTG, BaseNmeaClient::validateChecksum
  - Node `network_node` (C++) — Tests: sonar_nmea_0183_test.launch, test_sonar_nmea_0183_device_client.cpp — Functions: BaseNmeaClient::extractGGA, BaseNmeaClient::extractDBT, BaseNmeaClient::extractVTG, BaseNmeaClient::validateChecksum
- Package `state_controller`
  - Node `state_controller_node` (C++) — Tests: get_state_service_test.launch, test_get_state_service.cpp — Functions: get_state (service handler)
- Package `tf`
  - Node `tf_empty_listener` (C++) — Tests: tf_benchmark.cpp, tf_unittest.cpp, tf_unittest_future.cpp
  - Node `tf_echo` (C++) — Tests: tf_benchmark.cpp, tf_unittest.cpp, tf_unittest_future.cpp
  - Node `tf_change_notifier` (C++) — Tests: tf_benchmark.cpp, tf_unittest.cpp, tf_unittest_future.cpp
  - Node `tf_monitor` (C++) — Tests: tf_benchmark.cpp, tf_unittest.cpp, tf_unittest_future.cpp
  - Node `static_transform_publisher` (C++) — Tests: tf_benchmark.cpp, tf_unittest.cpp, tf_unittest_future.cpp
  - Node `transform_listener_unittest` (C++) — Tests: tf_benchmark.cpp, tf_unittest.cpp, tf_unittest_future.cpp, transform_listener_unittest.cpp, transform_listener_unittest.launch
  - Node `test_message_filter` (C++) — Tests: test_message_filter.cpp, test_message_filter.xml, tf_benchmark.cpp, tf_unittest.cpp, tf_unittest_future.cpp
  - Node `testListener` (C++) — Tests: testListener.cpp, tf_benchmark.cpp, tf_unittest.cpp, tf_unittest_future.cpp
  - Node `testBroadcaster` (C++) — Tests: testBroadcaster.cpp, tf_benchmark.cpp, tf_unittest.cpp, tf_unittest_future.cpp
  - Node `tf_speed_test` (C++) — Tests: tf_benchmark.cpp, tf_unittest.cpp, tf_unittest_future.cpp
- Package `video_recorder`
  - Node `video_recorder_node` (C++) — Tests: no tests detected
- Package `water_infiltration`
  - Node `water_infiltration.py` (Python) — Tests: no tests detected
- Package `wifi_file_transfer_config`
  - Node `wifi_file_transfer_config_node` (C++) — Tests: no tests detected
  - Behavior: applies Wi‑Fi config via `nmcli` and (re)activates connection

- echoboat_odometry_node (package `echoboat_odometry`)
  - Subscribes: `fix` (sensor_msgs/NavSatFix), `/imu/data` (sensor_msgs/Imu), `/velodyne_points` (sensor_msgs/PointCloud2), `/depth` (geometry_msgs/PointStamped)
  - Publishes: `odom` (nav_msgs/Odometry), `depth_ned` (geometry_msgs/PointStamped), TF `map → base_link`

- lidar_filtering_node (package `lidar_filtering`)
  - Subscribes: `velodyne_points` (sensor_msgs/PointCloud2)
  - Publishes: `filtered_lidar` (sensor_msgs/PointCloud2)

- video_recorder_node (package `video_recorder`)
  - Subscribes: `fix` (sensor_msgs/NavSatFix)
  - Purpose: video capture/overlay (no main ROS outputs)

- ins_piksi_node (package `ins_piksi`)
  - Subscribes: `fix` (sensor_msgs/NavSatFix)

Common topic names used across nodes: `fix`, `/imu/data`, `depth`, `speed`, `state`, `vitals`, `velodyne_points`.

## Additional Docs
- SLAM/Mapping: `cartographer.md`, `gmapping.md`
- Hardware and manuals: `docs/` (Devices, Firmware, PCB, User Manual, etc.)

## Practices
- Always source ROS and the workspace (`source /opt/ros/noetic/setup.bash` then `source src/workspace/devel/setup.bash`).
- When adding a package, follow standard Catkin layout.
- Keep secrets out of version control; `config.txt` contains placeholders by default.

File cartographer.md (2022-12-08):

1) extract these topics:

- /lidar
- /imu
- /gps

python3 tools/Edit-Rosbag/topic_extracter.py inputBag.bag outputBag.bag /imu /lidar /gps
```
python3 tools/Edit-Rosbag/topic_extracter.py ~/bigBag.bag ~/bag_4_cartographer.bag /velodyne_points /imu/data /fix
```

2) move lua file to cartographer workspace:
mv Poseidon/src/workspace/launch/Cartographer/echoboat2D.lua cartographer_workspace/install_isolated/share/cartographer_ros/configuration_files/echoboat2D.lua

3) move both launch files to cartographer workspace:
mv Poseidon/src/workspace/launch/Cartographer/demo_echoboat.launch cartographer_workspace/install_isolated/share/cartographer_ros/launch/demo_echoboat.launch
mv Poseidon/src/workspace/launch/Cartographer/echoboat.launch cartographer_workspace/install_isolated/share/cartographer_ros/launch/echoboat.launch

4) launch
source install_isolated/setup.bash
roslaunch cartographer_ros demo_echoboat.launch bag_filename:=/home/ubuntu/bag_4_cartographer.bag

cartographer gives error : 
F1128 14:37:07.504280 18835 sensor_bridge.cc:140] Check failed: msg->linear_acceleration_covariance[0] != -1 (-1 vs. -1) Your IMU data claims to not contain linear acceleration measurements by setting linear_acceleration_covariance[0] to -1. Cartographer requires this data to work. 

error is comming from ros_sbg_driver line 1031:
https://github.com/SBG-Systems/sbg_ros_driver/blob/ce60bb858dd19eb7a72913347c983a4d2d4ccbba/src/message_wrapper.cpp

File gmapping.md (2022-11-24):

To generate a map for autonomous navigation the Lidar cannot be tilted.
```
[ WARN] [1669048454.299272691, 1631302065.849523351]: Laser has to be mounted planar! Z-coordinate has to be 1 or -1, but gave: 0.74183
[ WARN] [1669048454.412238939, 1631302065.960249728]: Laser has to be mounted planar! Z-coordinate has to be 1 or -1, but gave: 0.74183
```

Two lidar will have to be used, one for the navigation and for scanning infrastructure.

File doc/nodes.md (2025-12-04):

# Nodes Overview

This list is generated from `src/workspace/src/*/nodes`. Keep it updated when nodes are added or renamed.

| Package | Node file | Notes |
| --- | --- | --- |
| sonar_dummy | [nodes/sonar_dummy_node.cpp](../src/workspace/src/sonar_dummy/nodes/sonar_dummy_node.cpp) | Dummy sonar node (C++) — see [doc](doc/nodes/sonar_dummy.md) |
| raspberrypi_vitals | [nodes/raspberrypi_vitals_node.cpp](../src/workspace/src/raspberrypi_vitals/nodes/raspberrypi_vitals_node.cpp) | Raspberry Pi vitals publisher (C++) — see [doc](doc/nodes/raspberrypi_vitals.md) |
| imu_null | [nodes/imu_null_node.cpp](../src/workspace/src/imu_null/nodes/imu_null_node.cpp) | IMU null node (C++) — see [doc](doc/nodes/imu_null.md) |
| hydroball_config_websocket | [nodes/hydroball_config_websocket_node.cpp](../src/workspace/src/hydroball_config_websocket/nodes/hydroball_config_websocket_node.cpp) | Hydroball config websocket bridge (C++) — see [doc](doc/nodes/hydroball_config_websocket.md) |
| logger | [nodes/logger_binary_node.cpp](../src/workspace/src/logger/nodes/logger_binary_node.cpp) | Logger binary node (C++) — see [doc](doc/nodes/logger_binary.md) |
| logger | [nodes/logger_text_node.cpp](../src/workspace/src/logger/nodes/logger_text_node.cpp) | Logger text node (C++) — see [doc](doc/nodes/logger_text.md) |
| gnss_dummy | [nodes/gnss_dummy_node.cpp](../src/workspace/src/gnss_dummy/nodes/gnss_dummy_node.cpp) | Dummy GNSS node (C++) — see [doc](doc/nodes/gnss_dummy.md) |
| gnss_zed_f9p | [nodes/gnss_zed_f9p_node.cpp](../src/workspace/src/gnss_zed_f9p/nodes/gnss_zed_f9p_node.cpp) | ZED-F9P GNSS node (C++) — see [doc](doc/nodes/gnss_zed_f9p.md) |
| video_recorder | [nodes/video_recorder_node.cpp](../src/workspace/src/video_recorder/nodes/video_recorder_node.cpp) | Video recorder node (C++) — see [doc](doc/nodes/video_recorder.md) |
| hydroball_data_websocket | [nodes/hydroball_data_websocket_node.cpp](../src/workspace/src/hydroball_data_websocket/nodes/hydroball_data_websocket_node.cpp) | Hydroball data websocket bridge (C++) — see [doc](doc/nodes/hydroball_data_websocket.md) |
| state_controller | [nodes/state_controller_node.cpp](../src/workspace/src/state_controller/nodes/state_controller_node.cpp) | State controller node (C++) — see [doc](doc/nodes/state_controller.md) |
| sonar_nmea_0183_tcp_client | [nodes/network_node.cpp](../src/workspace/src/sonar_nmea_0183_tcp_client/nodes/network_node.cpp) | Sonar NMEA 0183 network client (C++) — see [doc](doc/nodes/sonar_nmea_0183_tcp_client.md) |
| sonar_nmea_0183_tcp_client | [nodes/device_node.cpp](../src/workspace/src/sonar_nmea_0183_tcp_client/nodes/device_node.cpp) | Sonar NMEA 0183 device client (C++) — see [doc](doc/nodes/sonar_nmea_0183_tcp_client.md) |
| diagnostics | [nodes/diagnostics_websocket_node.cpp](../src/workspace/src/diagnostics/nodes/diagnostics_websocket_node.cpp) | Diagnostics websocket bridge (C++) — see [doc](doc/nodes/diagnostics.md) |
| imu_dummy | [nodes/imu_dummy_node.cpp](../src/workspace/src/imu_dummy/nodes/imu_dummy_node.cpp) | Dummy IMU node (C++) — see [doc](doc/nodes/imu_dummy.md) |
| gnss_mosaic_x5 | [nodes/gnss_mosaic_x5_node.cpp](../src/workspace/src/gnss_mosaic_x5/nodes/gnss_mosaic_x5_node.cpp) | GNSS Mosaic X5 node (C++) — see [doc](doc/nodes/gnss_mosaic_x5.md) |
| lidar_filtering | [nodes/lidar_filtering_node.cpp](../src/workspace/src/lidar_filtering/nodes/lidar_filtering_node.cpp) | Lidar filtering node (C++) — see [doc](doc/nodes/lidar_filtering.md) |
| hydroball_files_websocket | [nodes/hydroball_files_websocket_node.cpp](../src/workspace/src/hydroball_files_websocket/nodes/hydroball_files_websocket_node.cpp) | Hydroball files websocket bridge (C++) — see [doc](doc/nodes/hydroball_files_websocket.md) |
| ins_piksi | [nodes/ins_piksi_node.cpp](../src/workspace/src/ins_piksi/nodes/ins_piksi_node.cpp) | INS Piksi node (C++) — see [doc](doc/nodes/ins_piksi.md) |

Per-node docs live in `doc/nodes/*.md` (update as details become available).

When modifying a node, update this table if paths or roles change, and ensure inline comments/docstrings remain accurate.

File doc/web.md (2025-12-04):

# Web UI Pages

Primary HTML pages under `www/webroot/`. Per-page docs live in `doc/web/*.md`.

| Page | Purpose | Doc |
| --- | --- | --- |
| [index.html](../www/webroot/index.html) | Dashboard entry point | [doc/web/index.md](doc/web/index.md) |
| [status.html](../www/webroot/status.html) | Status view | [doc/web/status.md](doc/web/status.md) |
| [diagnostics.html](../www/webroot/diagnostics.html) | Diagnostics view | [doc/web/diagnostics.md](doc/web/diagnostics.md) |
| [data.html](../www/webroot/data.html) | Data view | [doc/web/data.md](doc/web/data.md) |
| [map.html](../www/webroot/map.html) | Map view | [doc/web/map.md](doc/web/map.md) |
| [settings.html](../www/webroot/settings.html) | Settings view | [doc/web/settings.md](doc/web/settings.md) |
| [calibration.html](../www/webroot/calibration.html) | Calibration view | [doc/web/calibration.md](doc/web/calibration.md) |
| [goal.html](../www/webroot/goal.html) | Goal/mission view | [doc/web/goal.md](doc/web/goal.md) |

Associated scripts live in `www/webroot/js/*.js`; update corresponding JS tests and docs when behavior changes.

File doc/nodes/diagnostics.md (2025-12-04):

# diagnostics_websocket_node

## Overview
- ROS node name: `diagnostics`.
- Hosts a WebSocket server (port `9099`) that serves two commands to the web UI:
  - `updateDiagnostic`: runs all diagnostics tests and returns the results.
  - `getRunningNodes`: returns the list of currently running ROS nodes.
- Uses a set of diagnostic tests (GNSS comm/fix, IMU comm/calibration, sonar comm, clock, API connection, serial number pattern, GNSS binary stream).

## Inputs
- Relies on diagnostics test classes to query ROS state (topics/services); no ROS topics are directly subscribed in this node.

## Outputs (WebSocket messages)
- `diagnostics` array: produced on `updateDiagnostic` command. Each test calls `do_test()` then serializes itself into JSON via `to_json`.
- `running_nodes` array: produced on `getRunningNodes`, listing node names from `ros::master::getNodes()`.

## Behavior
- WebSocket server with no TLS, reuse-addr enabled, logging disabled.
- On each command, builds a JSON document and broadcasts to all connected clients.
- Stores connections in a set protected by a mutex; `send_json` broadcasts to all.
- `stop()` cleanly stops listening and closes connections when the node shuts down.

## Parameters
- Port is hardcoded to `9099` in `diagnostics_websocket_node.cpp`. Change the source to use a ROS param if needed.

## Usage
```bash
rosrun diagnostics diagnostics_websocket_node   # listens on 9099
```
- Open the web UI diagnostics page to issue `updateDiagnostic` / `getRunningNodes` commands.

## Notes / Caveats
- No authentication or TLS; keep on trusted networks.
- If new diagnostic tests are added/removed, update the list in `DiagnosticsServer` construction and this doc.
- Running node list depends on ROS master visibility; if master is remote or filtered, results may differ.

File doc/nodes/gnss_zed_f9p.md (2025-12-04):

# gnss_zed_f9p_node

## Overview
- ROS node name: `zedf9p`. Interfaces with a ZED-F9P GNSS receiver over serial, decodes UBX frames, publishes speed and diagnostics, and streams raw UBX bytes.
- Requires two args: `logPath` and `serialDevice` (e.g., `/dev/ttyACM0`). Exits if missing/empty.
- Runs serial read loop; waits for a valid GNSS fix (status >= 0 on `/fix`) before processing frames.

## Subscriptions
- `fix` (`sensor_msgs/NavSatFix`): used only to detect that GNSS time is bootstrapped (status >= 0 sets `bootstrappedGnssTime`).

## Publications
- `speed` (`nav_msgs/Odometry`): `twist.twist.linear.y` set to ground speed (km/h) from UBX NAV-PVT `groundSpeed` (mm/s).
- `gnss_bin_stream` (`binary_stream_msg/Stream`): raw UBX frames (sync, header, payload, checksum) with `timeStamp` (ns).
- `gnss_status` (`gnss_status_msg/GnssDiagnostic`):
  - `fix_type` ← PVT fixType
  - `diff_soln` ← PVT flags bit 2
  - `carr_soln` ← PVT flags bits 6–7
  - `num_sv` ← PVT nbSatellites
  - `horizontal_accuracy` ← PVT horizontalAccuracy (mm → m)
  - `vertical_accuracy` ← PVT verticalAccuracy (mm → m)

## Behavior
- Serial config: `/dev/...` opened with termios at 460800 baud, 8N1, no flow control.
- Parse loop:
  - Read UBX sync (0xB5 0x62), header, payload, checksum.
  - Validate checksum over header+payload.
  - For NAV-PVT (class 0x01, id 0x07): publish speed and diagnostics; also forward raw frame on `gnss_bin_stream`.
  - Other frames currently ignored (logged to `gnss_bin_stream` only if NAV-PVT).
- Rotation/logging to files is not used here (leftover members for logPath, tmpFolder, rotation interval).

## Parameters / Args
- argv[1]: `logPath` (required; currently only used in INFO logging)
- argv[2]: `serialDevice` (required; e.g., `/dev/ttyACM0`)
- Rotation interval is defined but unused; no ROS params exposed.

## Notes
- Ensure serial device is accessible (permissions). If checksum errors occur, they’re logged.
- Update this doc if additional UBX messages are decoded or if file logging is enabled.

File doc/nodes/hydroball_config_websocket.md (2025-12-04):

# hydroball_config_websocket_node

## Overview
- Websocket-based configuration server for Hydroball. Bridges config between ROS and web UI on port 9004.
- Loads configuration from a file (path passed as argv[1]) at startup; persists updates back to that file.
- Broadcasts IMU static transform from stored offsets and publishes config key/value updates.
- Provides services to read configuration and zero IMU offsets.
- Node name: `hydroball_config_websocket`.

## Published topics
- `configuration` (`setting_msg/Setting`): publishes key/value pairs when broadcasting config changes.

## Services offered
- `get_configuration` (`setting_msg/ConfigurationService`)
  - Request: `key` (string)
  - Response: `value` (string) if key exists.
- `zero_imu_offsets` (`setting_msg/ImuOffsetService`)
  - Reads current IMU orientation from `state_controller/get_state`; stores negated yaw/pitch/roll as offsets; writes config file; rebroadcasts config and IMU transform.

## Services used
- Client: `get_state` (`state_controller_msg/GetStateService`) to fetch current IMU orientation for zeroing.

## WebSocket API (port 9004)
- Commands (JSON):
  - `{"command":"getConfiguration"}` → server sends current configuration as array of `{key,value}`.
  - `{"command":"saveConfiguration","configuration":[{"key":"...","value":"..."}]}` → updates stored configuration, writes file, broadcasts config and IMU transform, updates hotspot SSID if changed.
  - `{"command":"zeroImu"}` → invokes zero_imu_offsets service logic.
- Connections are tracked; on stop, the server closes all connections with a normal close frame.

## File I/O
- Reads config from `configFilePath` (argv[1]) on startup. Each line: `<key> <value>` (or `<key> <value...>` if spaces present).
- Writes config back on save/zero operations.

## IMU transform broadcast
- If `headingOffset`, `pitchOffset`, and `rollOffset` exist and parse as doubles, broadcasts a static transform `base_link` → `imu` using those offsets (RPY in degrees).

## Network/Hotspot update
- If `hotspotSSID` changes, updates NetworkManager connection `Hotspot` via `nmcli` (down/up) and verifies SSID.

## Parameters / arguments
- argv[1]: path to configuration file (required). Node exits with error if missing.
- Port: hardcoded to 9004 in node main when starting the websocket server.
- No ROS params used.

## Behavior
- Main node (`hydroball_config_websocket_node.cpp`): expects config path arg; starts ConfigurationServer; runs websocket server on port 9004 in a separate thread; spins at 10 Hz until shutdown; then stops server and joins thread.

## Notes
- Update this doc if commands, config schema, or services change. Ensure config file path is provided at launch. Credentials/SSIDs are handled via the config file; avoid committing real secrets.

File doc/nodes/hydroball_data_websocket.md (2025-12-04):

# hydroball_data_websocket_node

## Overview
- ROS node name: `hydroball_websocket_controller`.
- Hosts a WebSocket server (default port `9002`) that streams telemetry from ROS to the web UI and proxies logging control commands.
- Telemetry payloads are JSON assembled from `state_controller_msg/State` and `gnss_status_msg/GnssDiagnostic`.

## Inputs
- `state` (`state_controller_msg/State`): position, imu, depth, vitals; each field is checked for valid header/seq before inclusion.
- `gnss_status` (`gnss_status_msg/GnssDiagnostic`): forwarded as a separate JSON message (`type: "gnss_status"`).
- TF: transform `base_link` → `imu` is used to compute heading/pitch/roll (via `QuaternionUtils::applyTransform`).
- Services:
  - `get_logging_status` (`logger_service/GetLoggingStatus`)
  - `toggle_logging` (`logger_service/ToggleLogging`)
  - `get_logging_mode` (`logger_service/GetLoggingMode`)
  - `set_logging_mode` (`logger_service/SetLoggingMode`, wired but not used in current commands)

## Outputs (WebSocket messages)
- Telemetry JSON (sent when `state.stamp` advances > 200 ms):
  - `position`: `[lon, lat]` or empty array if no fix.
  - `gnssFix`: NavSatStatus status code.
  - `attitude`: `[heading_deg(0-360), pitch_deg, roll_deg]` or empty if IMU missing/TF fails.
  - `depth`: `[z]` or empty.
  - `vitals`: `[cpuTemp, cpuLoad, freeRam, freeHdd, uptime, temp, voltage, humidity, ledState]` plus `status` string.
  - `recordingInfo`: `{status: bool}` and `loggingMode`: `{the_mode_is: int}` appended per broadcast.
- GNSS status JSON: `{type:"gnss_status", fix_type, diff_soln, carr_soln, num_sv, h_acc, v_acc}` pushed on every `gnss_status` message.

## Commands (WebSocket client → server)
- `{"command":"getLoggingInfo"}` → replies with current `recordingInfo` and `loggingMode`.
- `{"command":"startLogging"}` → calls `toggle_logging` (enable), then replies with updated logging info.
- `{"command":"stopLogging"}` → calls `toggle_logging` (disable), then replies.
- (Mode change not exposed yet; `set_logging_mode` client exists but unused.)

## Behavior
- Maintains active client set; broadcasts telemetry to all connections.
- If logging mode is `1` (auto) and recording is off when sending telemetry, attempts to enable logging before sending.
- `run(port)` starts the ASIO server; node spins `ros::spin()` while server runs in a separate thread; on shutdown calls `stop()` to close connections.

## Usage
```bash
rosrun hydroball_data_websocket hydroball_data_websocket_node   # listens on 9002
```
- Ensure `logger_service` is running so logging services are available.
- Avoid port conflicts; adjust source if a different port is needed.

## Notes / Caveats
- No authentication on the WebSocket server; keep it on trusted networks.
- Attitude relies on TF `base_link`→`imu`; missing TF leads to empty attitude array (warns).
- Telemetry rate is gated at ~5 Hz by timestamp delta; burstier `state` messages are dropped in between.
- Update this doc if message schema or command set changes.

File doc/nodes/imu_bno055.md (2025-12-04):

# bno055_i2c_node / bno055_i2c_calibration

## Overview
- ROS nodes: `bno055_i2c_node` (runtime) and `bno055_i2c_calibration` (one-shot calibration). Launch files place them in the `imu` namespace.
- Driver reads a Bosch BNO055 over I2C, applies saved calibration offsets, publishes fused and raw IMU data plus diagnostics, and exposes reset/calibrate services.
- Calibration node monitors calibration status until complete, then writes offsets to a file for reuse by the runtime node.

## Topics (published)
- `data` (`sensor_msgs/Imu`): fused orientation (unit quaternion), fused linear acceleration (m/s^2), angular velocity (rad/s) derived from fused data.
- `raw` (`sensor_msgs/Imu`): raw linear acceleration (m/s^2) and angular velocity (rad/s) direct from sensor registers.
- `mag` (`sensor_msgs/MagneticField`): magnetic field (scaled by 1/16 from raw counts).
- `temp` (`sensor_msgs/Temperature`): onboard IMU temperature in °C.
- `status` (`diagnostic_msgs/DiagnosticStatus`): calibration/self-test/interrupt/system status/errors (published every 50 spins).

## Services (provided)
- `calibrate` (`std_srvs/Trigger`): placeholder (returns true; main calibration flow is via `bno055_i2c_calibration`).
- `reset` (`std_srvs/Trigger`): soft reset + reapply calibration + mode setup.

## Parameters
- `~device` (string, default `/dev/i2c-1`): I2C device path.
- `~address` (int, default `0x28`): I2C address (`BNO055_ADDRESS_A`).
- `~frame_id` (string, default `imu`): frame set on all published messages.
- `~calibrationFile` (string, default `/opt/Poseidon/calibration.dat`): binary offsets file; loaded on startup and written by calibration node when fully calibrated.
- `~rate` (int, default `100`): main loop frequency for `bno055_i2c_node` (watchdog refreshed on successful spins).

## Behavior
- On start: opens I2C device, verifies chip ID, loads calibration offsets if the file exists, remaps axes to ENU, sets operation mode to `NDOF`, and begins publishing.
- Each spin reads two I2C blocks (0x20 + 0x13 bytes), publishes fused/raw IMU, mag, and temperature messages; publishes diagnostics periodically.
- Watchdog is refreshed only when a spin succeeds; I2C read failures will stop refresh and let the watchdog terminate the node.
- `bno055_i2c_calibration`: opens the sensor, enters a loop printing calibration progress; when all sensors are calibrated (`0xFF`), dumps the calibration block to `calibrationFile` and exits.

## Usage
```bash
# Runtime
roslaunch imu_bno055 imu.launch          # starts bno055_i2c_node in ns=imu

# Calibration (collect offsets, writes calibrationFile)
roslaunch imu_bno055 calibrate.launch    # runs bno055_i2c_calibration until fully calibrated
```
- Ensure the I2C device and address match the hardware wiring.
- Persist the generated calibration file on the target so runtime can load it.

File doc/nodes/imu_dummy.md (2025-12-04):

# imu_dummy_node

## Overview
- ROS node name: `imu`.
- Publishes synthetic IMU orientation at 200 Hz on `imu/data` for testing/bring-up.
- Orientation is a smooth, time-varying quaternion derived from sin/cos of the sequence number.

## Outputs
- `imu/data` (`sensor_msgs/Imu`): orientation only.
  - Header: `seq` increments, `stamp` = now.
  - Orientation:
    - yaw = `sin(seq / π) * 30°`
    - pitch = `cos(seq / π) * 20°`
    - roll = `sin(seq / π) * 10°`
  - Angular velocity and linear acceleration are left at default zero.

## Inputs
- None.

## Parameters
- None; topic name and rate (200 Hz) are fixed in code.

## Behavior
- Main loop: compute orientation, publish IMU message, `ros::spinOnce()`, sleep at 200 Hz.
- Helper `message(seq, yaw, pitch, roll)` exists to publish arbitrary Euler angles if used by tests.

## Usage
```bash
rosrun imu_dummy imu_dummy_node
rostopic echo /imu/data
```

## Notes
- Intended for simulation/headless testing only; replace with a real IMU driver in production.
- Update this doc if noise models, params, or topic names change.

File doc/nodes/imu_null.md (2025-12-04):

# imu_null_node

## Overview
- Publishes a zeroed IMU orientation at high rate (200 Hz) on `imu/data`.
- Useful as a null/identity IMU source for testing.
- Node name: `imu`.

## Published topics
- `imu/data` (`sensor_msgs/Imu`):
  - `orientation`: RPY = (roll=0, pitch=0, yaw=0) converted to quaternion.
  - `header.seq`: incremented each publish.
  - `header.stamp`: `ros::Time::now()`.

## Services / subscriptions
- None.

## Parameters
- None; outputs are hardcoded zeros.

## Behavior
- Constructor: advertises `imu/data`.
- Main loop (200 Hz): `run()` builds `sensor_msgs/Imu` with zero orientation and publishes it.
- `message()` helper can publish arbitrary RPY if invoked manually (not used in main loop).

## Notes
- Update this doc if the node gains parameters, covariance, or additional fields.

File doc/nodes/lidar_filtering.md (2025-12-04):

# lidar_filtering_node

## Overview
- ROS node name: `lidar_filtering`.
- Filters incoming `velodyne_points` by horizontal angle window and Euclidean distance, publishes filtered cloud on `filtered_lidar`.

## Inputs
- `velodyne_points` (`sensor_msgs/PointCloud2`): source LiDAR point cloud.

## Outputs
- `filtered_lidar` (`sensor_msgs/PointCloud2`): points that pass both filters, header copied from input.

## Arguments (required)
Provided as argv (no ROS params):
1) `minAngle` (deg) — points with heading between minAngle and maxAngle are **removed**.
2) `maxAngle` (deg)
3) `minDistance` (m) — points closer than this are removed.
4) `maxDistance` (m) — points farther than this are removed.

## Behavior
- Converts incoming PointCloud2 to PointCloud for iteration.
- For each point:
  - Compute heading `theta = atan2(y,x)` in degrees; discard if `theta` in (minAngle, maxAngle).
  - Compute distance `sqrt(x² + y² + z²)`; discard if `< minDistance` or `> maxDistance`.
- Remaining points are re-packed into PointCloud2 and published.

## Usage
```bash
rosrun lidar_filtering lidar_filtering_node -30 30 0.5 50
```
- The above removes points in front sector (-30..30 deg) and outside 0.5–50 m.

## Notes / Caveats
- No frame transforms are applied; assumes input frame matches desired filtering frame.
- Filters are hardcoded via argv; update source to use ROS params if runtime tuning is needed.
- Update this doc if additional filters (e.g., elevation) are re-enabled.

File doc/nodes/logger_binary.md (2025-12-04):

# logger_binary_node

## Overview
- Binary logger node (ROS node name: `logger`) that writes GNSS/IMU/sonar/lidar/vitals/speed data to binary files and raw GNSS/sonar datagrams, with rotation and optional transfer.
- Requires an output folder path as argv[1]; exits with error if missing.
- Exposes a transfer service (via `LoggerBase::advertiseTransferService`).

## Topics/Subscribers (via LoggerBase callbacks)
- GNSS (`sensor_msgs/NavSatFix`): writes PACKET_POSITION.
- IMU (`sensor_msgs/Imu`): writes PACKET_ATTITUDE (heading/pitch/roll).
- Sonar (`geometry_msgs/PointStamped`): writes PACKET_DEPTH (x,y,z).
- Lidar (`sensor_msgs/PointCloud2`): writes PACKET_LIDAR (x,y,z for each point).
- Speed (`nav_msgs/Odometry`): writes PACKET_SPEED (KMH from twist.linear.y).
- Vitals (`raspberrypi_vitals_msg/sysinfo`): writes PACKET_VITALS (dynamic fields parsed from sysinfo.msg).

## Outputs / Files
- Binary log file: `<timestamp>.log` (packets for position/attitude/depth/lidar/speed/vitals).
- Raw GNSS datagrams: `<timestamp><gps_ext>` (fileExtensionForGpsDatagram).
- Raw Sonar datagrams: `<timestamp><sonar_ext>` (fileExtensionForSonarDatagram).
- Rotation: time-based (`logRotationIntervalSeconds` from LoggerBase); uses `init()/finalize()/rotate()`.
- Finalize moves files from tmp folder to output folder; optional zip+transfer if `activatedTransfer` and `can_reach_server()`.

## Services
- Transfer service advertised via `advertiseTransferService(nh)` (see LoggerBase for details).

## Behavior
- Main: requires argv[1]=outputFolder; constructs `LoggerBinary`, advertises transfer service, `ros::spin()`.
- `init()`: opens binary/raw files with timestamp names when GNSS time is bootstrapped and logging is enabled.
- `finalize()`: closes/moves files; optionally zips/transfers.
- `rotate()`: triggers finalize/init when rotation interval elapsed (checked on GNSS callback).
- Each callback ensures file open, writes packet with timestamp > last timestamp for that stream.
- Vitals writer dynamically reads field names from `/opt/Poseidon/src/workspace/src/raspberrypi_vitals_msg/msg/sysinfo.msg` at startup to emit name/value pairs.

## Parameters / Flags (inherited from LoggerBase)
- `loggerEnabled`, `bootstrappedGnssTime`, `enableGeofence`, `insideGeofence`, `logRotationIntervalSeconds`, `tmpLoggingFolder`, `outputFolder`, `activatedTransfer`, `fileExtensionForGpsDatagram`, `fileExtensionForSonarDatagram`, etc. (see LoggerBase).
- argv[1]: output folder (required).

## Notes
- Geofence check skips sonar writes when outside.
- Rotation is GNSS-driven (1 Hz) to limit CPU.
- Ensure `/opt/Poseidon/src/workspace/src/raspberrypi_vitals_msg/msg/sysinfo.msg` path is valid for vitals field discovery.

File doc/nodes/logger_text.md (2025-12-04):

# logger_text_node

## Overview
- Text logger node (ROS node name: `logger`) that writes GNSS/IMU/sonar/lidar/vitals/speed data to per-stream text files plus raw GNSS/sonar datagrams, with rotation and optional transfer.
- Requires an output folder path as argv[1]; uses `;` as the default separator.
- Exposes a transfer service (via `LoggerBase::advertiseTransferService`).

## Topics/Subscribers (via LoggerBase callbacks)
- GNSS (`sensor_msgs/NavSatFix`): `_gnss.txt` (Timestamp, Longitude, Latitude, EllipsoidalHeight, Status, Service).
- IMU (`sensor_msgs/Imu`): `_imu.txt` (Timestamp, Heading, Pitch, Roll).
- Sonar (`geometry_msgs/PointStamped`): `_sonar.txt` (Timestamp, Depth); geofence check skips if outside.
- Lidar (`sensor_msgs/PointCloud2`): `_lidar.txt` (Timestamp, followed by x y z triples).
- Speed (`nav_msgs/Odometry`): `_speed.txt` (Timestamp, Speed from twist.linear.y).
- Vitals (`raspberrypi_vitals_msg/sysinfo`): `_vitals.txt` (Timestamp, CPU Temp, CPU Used, FREE RAM, FREE HDD, Uptime, Humidity, System Temp, Supply Voltage) every >60s; headers derived from `sysinfo.msg`.
- Raw GNSS/sonar datagrams: binary files with configured extensions.

## Outputs / Files
- Text files per stream in temp folder, then moved to output folder on finalize/rotate:
  - `<date>_gnss.txt`, `<date>_imu.txt`, `<date>_sonar.txt`, `<date>_lidar.txt`, `<date>_speed.txt`, `<date>_vitals.txt`
- Raw datagrams: `<date><gps_ext>`, `<date><sonar_ext>`
- Rotation: time-based (`logRotationIntervalSeconds` from LoggerBase); uses `init()/finalize()/rotate()`.
- Finalize closes/moves files; optional zip+transfer if `activatedTransfer` and `can_reach_server()`.

## Services
- Transfer service advertised via `advertiseTransferService(nh)` (see LoggerBase).

## Parameters / Args
- argv[1]: output folder (required).
- Separator: constructor default `";"` (hardcoded in node main).
- Other flags/paths inherited from LoggerBase (e.g., `loggerEnabled`, `bootstrappedGnssTime`, `enableGeofence`, rotation interval, temp/output folders, transfer flags, datagram extensions).

## Behavior
- Main: requires output folder; constructs `LoggerText` with separator `;`, advertises transfer service, `ros::spin()`.
- `init()`: opens all text files + raw GNSS/sonar files with timestamped names when GNSS time is bootstrapped and logging enabled.
- `finalize()`: closes/moves files; optionally zips/transfers.
- `rotate()`: time-based rotation checked on GNSS callback.
- Callbacks write formatted lines with timestamps; enforce monotonic timestamps per stream to avoid duplicates.

## Notes
- Geofence check skips sonar writes when outside.
- Vitals header is read from `/opt/Poseidon/src/workspace/src/raspberrypi_vitals_msg/msg/sysinfo.msg`; ensure path is valid.
- Update if file formats, fields, or rotation logic change.

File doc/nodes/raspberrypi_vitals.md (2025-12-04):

# raspberrypi_vitals_node

## Overview
- Publishes Raspberry Pi vitals at 1 Hz on `vitals` (CPU temp/load, RAM/HDD usage, uptime, humidity/temperature/voltage via I2C service, LED state, status).
- Node name: `hbv`.
- Uses local file/proc reads for system metrics, and an I2C controller service for environmental/battery readings and LED control.

## Published topics
- `vitals` (`raspberrypi_vitals_msg/sysinfo`):
  - `cputemp`: `/sys/class/thermal/thermal_zone0/temp` (°C)
  - `cpuload`: `/proc/loadavg` normalized by 8 cores (%)
  - `freeram`: `/proc/meminfo` free/total (%)
  - `freehdd`: `df --output=pcent /` inverted (% free)
  - `uptime`: `/proc/uptime` first value (seconds)
  - `humidity`, `temperature`, `voltage`, `ledstate`: from I2C service calls (see below)
  - `status`: text set by warning/critical checks (“Normal” or warning/critical messages)

## Services used
- Client: `i2c_controller_service` (`i2c_controller_service/i2c_controller_service`)
  - Actions requested:
    - `get_humidity` → `humidity`
    - `get_temperature` → `temperature`
    - `get_voltage` → `voltage`
    - `get_led_state` → `ledstate`
    - `led_error` (triggered on critical)
    - `led_warning` (triggered on warning)
  - On service failure: `humidity/temperature/voltage` set to `-555.0` sentinel.

## Status thresholds
- Critical (sets status, calls `led_error`):
  - `freehdd < 5%` (and >0)
  - `voltage <= 11.7V` (and >0)
  - `voltage >= 15.4V`
  - `cputemp >= 80°C`
- Warning (sets status, calls `led_warning`):
  - `voltage <= 15.4V` and >13.5V (charging)
  - `voltage <= 11.9V` and >0 (low)
  - `freehdd < 20%` and >0 (low space)
  - `cputemp >= 75°C` (high temp)
- Otherwise: status “Normal”.

## Parameters / configuration
- None via ROS params. Debug flags are hardcoded (`debug_mode`, `debug_mode_warning_critical`).

## Behavior
- Constructor: advertises `vitals`, creates I2C service client, waits for service.
- Main loop (1 Hz): read system metrics, call I2C actions, evaluate status/LED, publish `sysinfo`.

## Notes
- Update this doc if adding parameters, changing thresholds, or altering published fields/topics.

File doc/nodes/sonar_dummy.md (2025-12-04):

# sonar_dummy_node

## Overview
- Simulated sonar depth publisher for testing.
- Runs at 1 Hz and emits a sine-wave depth value (`sin(seq) * 30`) on the `depth` topic.
- On startup, queries configuration via `setting_msg/ConfigurationService` for optional sonar config values (stored locally, not currently used in the published message).

## Published topics
- `depth` (`geometry_msgs/PointStamped`): `point.z` set to simulated depth; header.seq incremented each publish; header.stamp = `ros::Time::now()`.

## Services used
- Client: `get_configuration` (`setting_msg/ConfigurationService`)
  - Request: `key` (string)
  - Response: `value` (string), parsed as `uint8_t`
  - Keys queried: `sonarStartGain`, `sonarRange`, `sonarAbsorbtion`, `sonarPulseLength`.

## Parameters / Config keys
- Retrieved via `get_configuration` service:
  - `sonarStartGain` (uint8_t), default 0x06
  - `sonarRange` (uint8_t), default 32
  - `sonarAbsorbtion` (uint8_t), default 0x14 (0.2 dB for 675 kHz)
  - `sonarPulseLength` (uint8_t), default 150

## Behavior
- Main loop (`sonar_dummy_node.cpp`):
  - Initialize ROS node `sonar`.
  - Construct `Sonar` (advertises publisher, config client, loads config).
  - Loop at 1 Hz: call `run()` → publish simulated depth; `ros::spinOnce()`; sleep.

## Notes
- If the configuration service is unavailable, config values fall back to the defaults above.
- Extend this node by replacing the sine generator with real sensor input, and by applying the retrieved config to the published data if needed.

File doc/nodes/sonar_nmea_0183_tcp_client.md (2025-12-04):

# sonar_nmea_0183_tcp_client (network_node, device_node)

## Overview
- Provides two entry points:
  - `nmea_network` (TCP client): connects to an NMEA-0183 TCP stream (default 127.0.0.1:5000).
  - `nmea_device` (serial client): reads NMEA-0183 from a serial device (default `/dev/sonar`), configurable baud rate.
- Parses depth (DBT/DPT/ADS), GNSS position (GGA), and speed/course (VTG), publishing ROS topics for downstream consumers.

## Published topics
- `depth` (`geometry_msgs/PointStamped`): depth in meters from DBT/DPT/ADS.
- `fix` (`sensor_msgs/NavSatFix`): position from GGA. Status set to -1/0/2 for no fix/GPS/DGPS.
- `speed` (`nav_msgs/Odometry`): `twist.twist.linear.y` set to ground speed km/h from VTG.

## Subscribed topics
- `configuration` (`setting_msg/Setting`) — device mode only: watches for `sonarSerialBaudRate` updates and reapplies the baud rate.

## Services used
- `get_configuration` (`setting_msg/ConfigurationService`) — device mode only: initial baud rate lookup (`sonarSerialBaudRate`).

## Parameters
### nmea_network
- `ip_address` (string, default `127.0.0.1`)
- `port` (int, default `5000`)

### nmea_device (under `/Sonar/` namespace)
- `/Sonar/device` (string, default `/dev/sonar`)
- `/Sonar/useDepth` (bool, default true) — currently depth always published when parsed.
- `/Sonar/usePosition` (bool, default false) — currently position always published when parsed.
- `/Sonar/useAttitude` (bool, default false) — attitude not parsed (reserved).
- `/Sonar/useAttitude` is reserved; no attitude sentences handled today.

### Serial baud rate (device mode)
- `sonarSerialBaudRate` (from configuration service) defaults to 9600 on missing/invalid value. Applied with `termios`.

## Behavior
- Checksum validation:
  - Each NMEA line is checksum-validated before parsing; invalid lines log `checksum error` and are skipped.
- Parsing:
  - GGA → publishes `fix` with converted lat/lon (deg/min to decimal), altitude, and status.
  - DBT/DPT/ADS → publishes `depth` (meters).
  - VTG → publishes `speed` with km/h.
- TCP mode:
  - Connects, sets a 5s recv timeout, reads char-by-char, and reconnects on failure with 1 Hz retry.
- Serial mode:
  - Opens device, sets baud rate from config service, listens for config updates to adjust baud, and reads char-by-char.
- State:
  - Sequence numbers increment per message type; timestamps set to `ros::Time::now()` on publish.

## Usage
```bash
# TCP client
rosrun sonar_nmea_0183_tcp_client network_node _ip_address:=192.168.0.10 _port:=5000

# Serial client
rosrun sonar_nmea_0183_tcp_client device_node _Sonar/device:=/dev/ttyUSB0
```

## Notes / Caveats
- No authentication; keep the TCP source on a trusted network.
- Char-by-char reading is inefficient but simple; may drop data if stream is very high rate.
- Attitude sentences are not parsed; `useAttitude` is a placeholder.
- Update this doc if additional NMEA sentences or params are added.

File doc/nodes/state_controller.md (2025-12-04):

# state_controller_node

## Overview
- ROS node name: `stateControl`.
- Aggregates navigation, attitude, depth, and vitals into a single `state_controller_msg/State` message and republishes it on `state`.
- Exposes a service to fetch the latest state snapshot.

## Inputs
- `fix` (`sensor_msgs/NavSatFix`): GNSS position. If `status.service > 0`, stored in `state.position` and timestamp updated.
- `/imu/data` (`sensor_msgs/Imu`): attitude; copied to `state.imu` and timestamp updated.
- `depth` (`geometry_msgs/PointStamped`): depth; copied to `state.depth` and timestamp updated.
- `vitals` (`raspberrypi_vitals_msg/sysinfo`): system vitals; copied to `state.vitals` and timestamp updated.

## Outputs
- `state` (`state_controller_msg/State`): republished on every input update. Fields include the most recent copies of position/imu/depth/vitals; `stamp` is set to the last message time received.

## Services
- `get_state` (`state_controller_msg/GetStateService`): returns the current `State`.

## Behavior
- On any incoming message, stores the data under a mutex, updates `stamp`, and publishes `state`.
- Initializes `position.status.status` to `-1` so consumers know there is no fix yet.
- No throttling or filtering; a future Kalman or rate limiter could be added (TODO in code).

## Parameters
- None; topic names and queue sizes are hardcoded in the constructor.

## Usage
```bash
rosrun state_controller state_controller_node
# listen on 'state' or call:
rosservice call /get_state
```

## Notes
- Assumes publishers for `fix`, `/imu/data`, `depth`, and `vitals` are already running.
- Extend this doc if rate limiting, filtering, or additional fields are added.

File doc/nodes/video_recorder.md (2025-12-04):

# video_recorder_node

## Overview
- ROS node name: `video_recorder`.
- Captures frames from the default camera (`/dev/video0`) and writes PNGs to a temporary folder, then moves them to the requested output folder after stamping EXIF GPS tags.
- GPS tags are interpolated linearly between the two most recent `NavSatFix` samples to approximate per-frame positions.

## Inputs
- `fix` (`sensor_msgs/NavSatFix`): GNSS samples (longitude, latitude, altitude) used to tag captured images. Two consecutive samples are kept to interpolate EXIF coordinates for all frames taken between them.

## Outputs
- No ROS topics/services produced. Artifacts are PNG files saved under the provided output folder, with EXIF fields:
  - `GPSMapDatum` = `WGS-84`
  - `GPSLongitude`, `GPSLatitude`, `GPSAltitude` set from interpolated GNSS.

## Parameters / Arguments
- `argv[1]` (required): output folder path. A trailing `/` is added if missing.
- Camera: hardcoded to index `0` via OpenCV.
- Temp folder: `/home/ubuntu/temp/` (frames are written here before EXIF tagging and move).

## Behavior
- On startup, opens the camera. If it cannot be opened, logs an error.
- Capture loop (`run`):
  - Reads frames continuously.
  - If at least one GNSS sample is buffered, writes `image<N>.png` into the temp folder.
  - `spinOnce()` is called each loop to process callbacks.
- GNSS callback:
  - Maintains a two-sample queue. Once two samples exist, calls `interpolateCoord()`.
- `interpolateCoord()`:
  - Lists all files in the temp folder, sorts them, and linearly interpolates coordinates across file count.
  - Adds EXIF GPS tags to each file, then moves it to the output folder (same filename).

## Usage
```bash
rosrun video_recorder video_recorder_node /path/to/output_folder
```
- Ensure `/home/ubuntu/temp/` exists and is writable, and the output folder exists or is creatable.
- Camera access may require `v4l2loopback` or udev permissions depending on hardware.

## Notes / Caveats
- No synchronization with IMU; only GNSS is used.
- Interpolation assumes constant velocity between two `NavSatFix` samples; tag accuracy depends on GNSS sample rate.
- No rotation/logging of video streams; only still PNG frames are produced.
- Update this doc if additional image formats, ROS params, or IMU integration are added.

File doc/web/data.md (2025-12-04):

# data.html

## Overview
- Download/management page for recorded log files.
- Talks to `hydroball_files_websocket_node` over WebSocket (`ws://<host>:9003`) to list, delete, and publish files.
- Provides pagination, search, select/delete, and a “Publish All Files” flow with status modal.

## Data Source (WebSocket messages)
- Endpoint: `ws://<host>:9003` (no auth).
- Expected messages:
  - File list: `{fileslist: [[filename, downloadUrl], ...]}` — rendered into a table with checkboxes and download links.
  - Publish status: `{publishstatus: "<step text>", done: <bool>}` — appended to the modal list; `done: true` enables the Close button.

## Commands (browser → WebSocket server)
- `{"f-list":"fileslist"}`: periodic poll every 500 ms to refresh the file list.
- `{"delete":"<filename>"}`: delete a selected file (driven by the delete modal).
- `{"publishfiles": true}`: trigger transfer of all files; server streams back `publishstatus` messages.

## UI / Behavior
- File table with pagination (per-page selector, first/prev/next/last) and client-side search filtering by filename.
- “Select All Files” toggles checkboxes for the current page; “Delete Selected Files” shows a confirmation modal then sends delete commands for checked rows on the current page.
- “Publish All Files” opens a modal and requests transfer; status lines accumulate until completion.
- Download links open/trigger download via the provided URLs in `fileslist`.
- File list refreshes on a fixed interval; table rebuilds when the list length changes.

## Scripts
- `js/dataScript.js`: WebSocket setup, periodic polling, file list rendering, delete/select/pagination/search handlers, publish modal updates.
- Shared includes: `js/script.js`, SB Admin 2 assets; no charts used.

## Notes / Caveats
- No authentication/TLS on the WebSocket; keep the UI on trusted networks.
- Delete is permanent (no undo). Poll interval is 500 ms; adjust if server load is a concern.

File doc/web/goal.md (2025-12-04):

# goal.html

## Overview
- Goal planner page for editing a list of waypoint goals and viewing them on a Leaflet map.
- Uses a WebSocket connection (hardcoded `ws://192.168.1.16:9003` in `goal.html`) to fetch and modify goals. Intended to align with the files WebSocket (`hydroball_files_websocket_node`); adjust host/port as needed.

## Data Source / Messages
- WebSocket sends/receives JSON arrays named `goal_planner`:
  - Incoming: `{goal_planner: [[lat, lon], ...]}` populates the table and draws the polyline on the map.
  - Outgoing commands (JSON strings built in JS):
    - `{"go_add":[lat, lon]}`: append a goal.
    - `{"go_ins":[index, lat, lon]}`: insert at a selected row (first checked box).
    - `{"go_del":[index]}`: delete selected goals (sent per checked row, iterating from end).
  - Selection toggling is client-side only; server must respond with an updated `goal_planner` to refresh the UI.

## UI / Behavior
- Map: Leaflet map with shapefile overlay (`/map/TM_WORLD_BORDERS-0.3.zip`), draws a red polyline through goals; pans to last goal on update.
- Table: lists latitude/longitude per goal with checkboxes.
- Buttons:
  - Select all/none (inverts current selection).
  - Delete (opens confirmation modal, then sends `go_del` for checked rows).
  - Add @ end (modal collects lat/lon, sends `go_add`).
  - Add @ line (modal collects lat/lon, inserts at first checked row via `go_ins`).
  - Edit button exists but is disabled (no implementation).
- No client-side validation beyond simple `isNaN` checks; incorrect values are silently ignored.

## Scripts
- Inline JS in `goal.html`: WebSocket connect, map setup, shapefile load, goal list rendering, add/insert/delete helpers.
- Leaflet plugins: `leaflet.shpfile.js` for border overlay; no external mapScript used here.

## Notes / Caveats
- WebSocket URL is hardcoded to `ws://192.168.1.16:9003`; update to `ws://<host>:9003` or the appropriate service before deployment.
- No authentication/TLS. Server must echo updated `goal_planner` for UI to refresh after commands.
- Edit flow is unimplemented; add validation and server-side checks as needed for production use.

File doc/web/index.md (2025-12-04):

# index.html

## Overview
- Landing dashboard for DataLogger. Shows live GNSS/IMU/sonar status, depth/attitude charts, and logging controls.
- Relies on `hydroball_data_websocket_node` (port `9002`) for telemetry and for start/stop logging commands.
- Uses SB Admin 2 layout + Chart.js + `gauge.min.js` for the heading gauge.

## Data Sources (WebSocket messages)
- Telemetry (`msg.telemetry`): longitude/latitude, `gnssFix`, `attitude` `[heading, pitch, roll]`, `depth` array, `vitals` (CPU, RAM, HDD free %, uptime, temps, voltage, humidity, LED state), `status` string.
- Recording info (`msg.recordingInfo`, `msg.loggingMode`): current logging state and mode (1=Always On, 2=Manual, 3=Speed-based).
- GNSS status (`msg.type == "gnss_status"`): `fix_type`, `num_sv`, `diff_soln`, `h_acc`, `v_acc`, shown in the GNSS widget.
- WebSocket endpoint: `ws://<host>:9002` (no auth).

## UI / Behavior
- Top bar: sidebar toggle, logo, record icon (mirrors recording state).
- Logging card: shows logging mode, start/stop button (visible only in manual mode), and current status text.
- Status banners: system status alert driven by `vitals[8]` and `status`; HDD low-space banner when `vitals[3] < 1`.
- GNSS card: lat/lon display, fix status colors; GNSS detail fields populated from `gnss_status` messages.
- IMU card: heading/pitch/roll values; heading radial gauge plus pitch/roll line chart (Chart.js).
- Sonar card: current depth and line chart (depth sign inverted for plotting).
- Loading overlay is shown until telemetry arrives; WebSocket reconnects after timeouts.

## Commands (browser → WebSocket server)
- `{"command":"getLoggingInfo"}`: fetch current logging state/mode (invoked on connect).
- `{"command":"startLogging"}`: request logging on.
- `{"command":"stopLogging"}`: request logging off.
- Logging buttons call these commands; button visibility is mode-dependent.

## Scripts
- `js/dashboardscript.js`: WebSocket connect/reconnect, telemetry parsing, widget updates, logging button logic.
- Shared includes: `js/poseidon.js`, `js/script.js`, Chart.js, `gauge.min.js`, Bootstrap/SB Admin 2 assets.

## Notes / Caveats
- No authentication on the WebSocket; keep the UI on trusted networks.
- Requires `hydroball_data_websocket_node` running with logging services available; otherwise logging buttons will not work.
- If TF/IMU/GNSS data are missing, cards show warnings and zeroed plots.

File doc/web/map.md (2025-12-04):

# map.html

## Overview
- Live map view (Leaflet) showing vessel track and depth-colored hotline.
- Consumes telemetry from `hydroball_data_websocket_node` (port `9002`) and configuration (geofence WKT) from `hydroball_config_websocket_node` (port `9004`).
- Adds bathymetry shapefile overlay (`map/ne_10m_bathymetry_L_0.zip`) and optional geofence polygon.

## Data Sources (WebSocket)
- Telemetry socket `ws://<host>:9002`: expects `{telemetry:{position:[lon,lat], depth:[z], vitals:[...], ...}}`.
  - Positions are appended to the track polyline; depth (index 0) feeds the hotline color scale.
  - Autopan keeps the map centered on the latest position unless toggled off.
- Config socket `ws://<host>:9004`: on open sends `{"command":"getConfiguration"}`; looks for `configuration` array entries and renders `geofence` (WKT) onto the map.

## UI / Behavior
- Track rendering: red polyline plus hotline heatmap; depth palette runs red→yellow→green→cyan→blue→purple→black.
- Geofence: WKT polygon drawn in green with fill, bounds-fit on load.
- Autopan toggle button (top-right Leaflet control) switches between following the current position and a static view; label updates to “Auto Pan On/Off”.
- Scale bar and simple legend (Bathymetry / Geofence).
- Shapefile overlay popup shows feature properties on click.

## Scripts
- `js/mapScript.js`: Leaflet init, shapefile load, telemetry/config WebSockets, geofence draw, track/hotline updates, autopan control.
- Leaflet plugins: `leaflet.hotline.js`, `leaflet.shpfile.js`, WKT helpers (`wicket`, `terraformer-wkt-parser`).

## Notes / Caveats
- WebSockets are unauthenticated; keep UI on trusted networks.
- Depth defaults to `0` if missing; hotline still plots but color may be misleading.
- Shapefile must exist at `www/webroot/map/ne_10m_bathymetry_L_0.zip`; missing file removes the base overlay but map still works.

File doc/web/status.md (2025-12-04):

# status.html

## Overview
- System status page showing vitals (uptime, CPU, RAM, disk, humidity, battery, internal temperature).
- Receives telemetry via `hydroball_data_websocket_node` (WebSocket `ws://<host>:9002`) and renders progress bars/labels.
- Uses SB Admin 2 layout; sidebar is shared with other pages.

## Data Source (WebSocket message)
- Expects JSON with `telemetry.vitals` (array from `state_controller_msg/State` forwarded by `hydroball_data_websocket_node`):
  - `vitals[0]` CPU temperature (°C)
  - `vitals[1]` CPU load (%)
  - `vitals[2]` free RAM (%); page displays used RAM as `100 - vitals[2]`
  - `vitals[3]` free HDD (%); page displays used disk as `100 - vitals[3]`
  - `vitals[4]` uptime (seconds)
  - `vitals[5]` internal temperature (°C) — hidden if `-555`
  - `vitals[6]` battery voltage (V) — hidden if `-555`
  - `vitals[7]` humidity (%) — hidden if `-555`
  - (Index 8 LED state exists in the websocket payload but is unused here.)

## UI / Behavior
- Uptime formatted as `D HH:MM:SS`.
- CPU load bar: green when <90%, red otherwise.
- CPU temperature bar: green <75°C, yellow 75–80°C, red >80°C.
- Memory bar shows usage (`100 - freeRam%`); green when free >10%, red otherwise.
- Disk bar shows usage (`100 - freeHdd%`); green >20% free, yellow 5–20%, red ≤5%.
- Humidity, battery, temperature bars are hidden if the value is `-555` (sensor not available). Otherwise:
  - Humidity: green <40%, yellow 40–60%, red >60%.
  - Battery: voltage-based coloring/width (danger ≤11.7V or ≥15.4V, warning 11.7–11.9V or 13.5–15.4V, success 11.9–13.5V).
  - Temperature (internal): green <60°C, yellow 60–75°C, red >75°C.
- A `systemStatus` alert element exists but is not populated by `statusScript.js`.

## Scripts
- `js/statusScript.js`: opens WebSocket, parses `telemetry.vitals`, updates bars/labels, hides optional sensors on sentinel values.
- Shared includes: `js/poseidon.js`, `js/script.js`, SB Admin 2, Chart.js, `gauge.min.js` (gauge not used on this page).

## Notes
- No authentication on the WebSocket; keep the UI on trusted networks.
- If telemetry is missing or malformed, the page leaves values unchanged/blank.

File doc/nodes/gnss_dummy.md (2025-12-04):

# gnss_dummy_node

## Overview
- Dummy GNSS publisher (ROS node name: `gnss`) for testing; publishes simulated `NavSatFix` at 1 Hz on `fix`.
- Coordinates follow a synthetic path with noise; status alternates to simulate fix quality.

## Published topics
- `fix` (`sensor_msgs/NavSatFix`):
  - `header.seq`: incremented per publish
  - `header.stamp`: `ros::Time::now()`, nsec forced to 0
  - `status.status` and `status.service`: set to the `status` argument passed to `talk()` (alternates)
  - `longitude`, `latitude`: synthetic path (sinusoidal + noise)
  - `altitude`: `sin(seq*42+100)*10` (ellipsoidalHeight)

## Behavior
- Main loop (1 Hz):
  - For 60 iterations: `talk(-1)` (e.g., no/invalid fix)
  - For next 30 iterations: `talk(1)` (e.g., good fix)
  - Then resets counter to 30 and repeats (50/50 bias toward good fix after first loop)
- `talk(int status)`:
  - Increments `sequenceNumber`
  - Perturbs longitude/latitude with noise and sinusoids; also sets a straight-path variant (latitude from distance/earth radius) at the end
  - Calls `message(seq, lon, lat, status)`
- `message(...)`: fills `NavSatFix` and publishes.

## Services / Subscriptions
- None.

## Parameters
- None; behavior hardcoded.

## Notes
- Update this doc if path/noise or status patterns change. Ensure `fix` topic consumers can handle alternating status values and synthetic coordinates.

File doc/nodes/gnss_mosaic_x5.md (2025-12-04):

# gnss_mosaic_x5_node

## Overview
- ROS node name: `mosaic-X5`.
- Reads Septentrio Mosaic-X5 SBF datagrams from a serial port and logs them to `.sbf` files.
- Waits for a valid GNSS fix on `fix` before starting, to ensure GNSS time is available.

## Inputs
- `fix` (`sensor_msgs/NavSatFix`): used only to gate startup; when `status.status >= 0`, logging begins.
- Serial port (argument): raw SBF stream from the receiver.
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

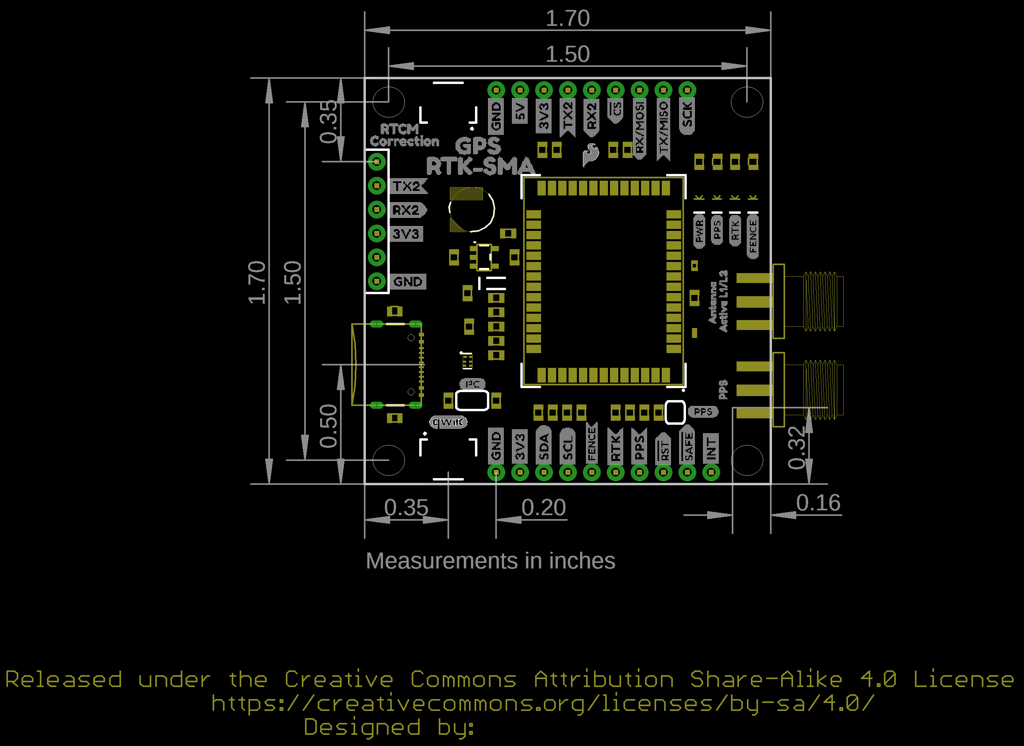
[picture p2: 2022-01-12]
docs/Devices/GPS/Zed-F9P/SparkFun-GPS-RTK-SMA-ZED-F9P_Board_Dimensions.png

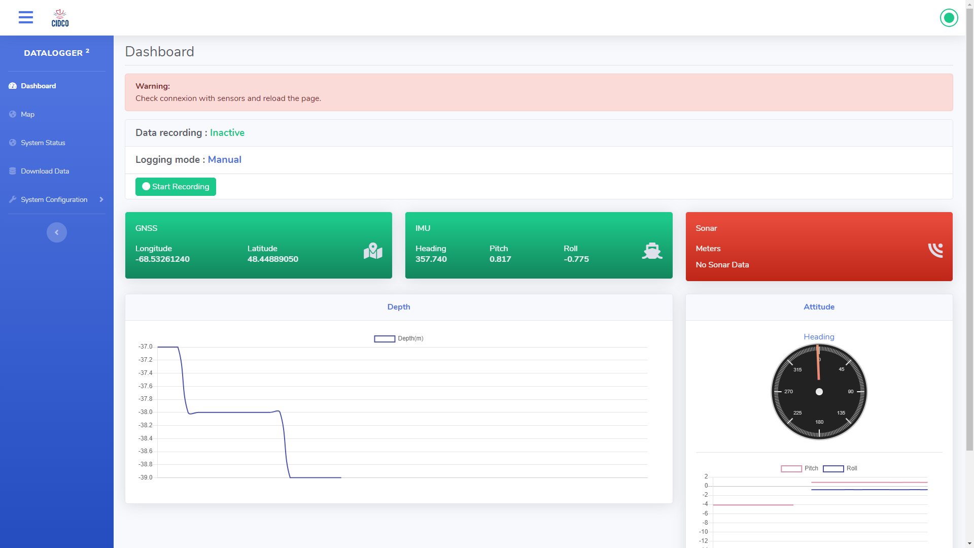
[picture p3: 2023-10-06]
docs/Web_site_screen_capture/Dashboard_no_sonar.png

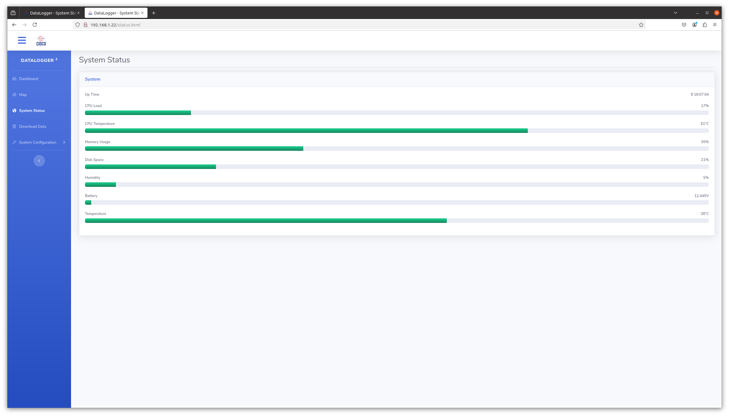
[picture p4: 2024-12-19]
docs/Web_site_screen_capture/System_Status_HB Gen B.png

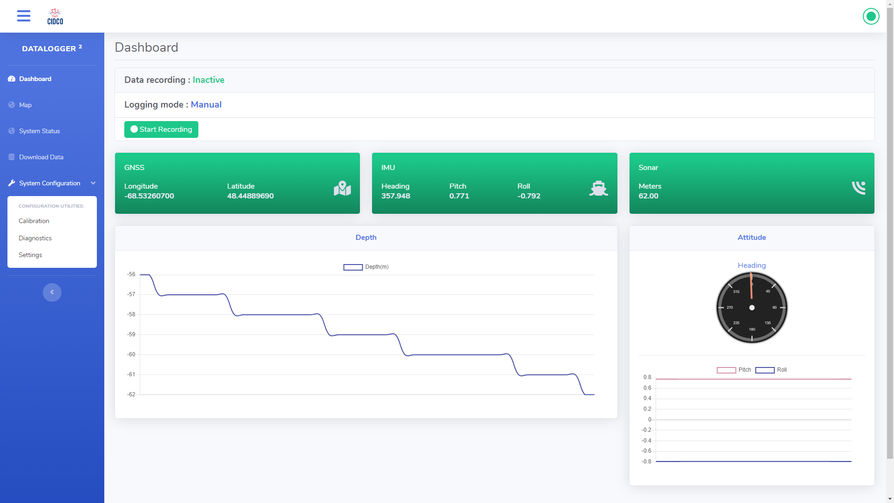
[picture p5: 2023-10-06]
docs/Web_site_screen_capture/Menu_expand.png

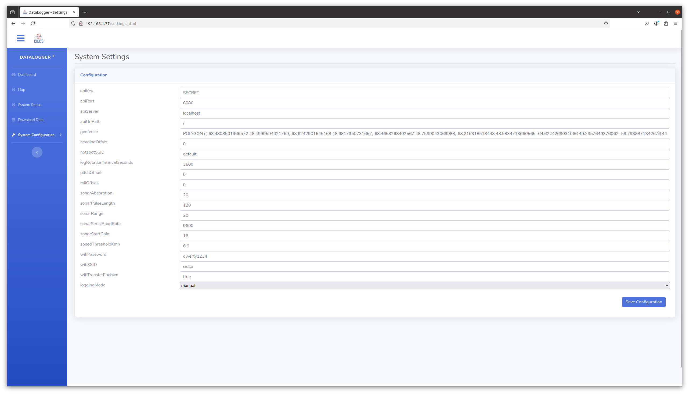
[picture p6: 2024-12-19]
docs/Web_site_screen_capture/System_Settings.png

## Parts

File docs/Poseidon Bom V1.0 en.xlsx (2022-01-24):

Projet Hydro B
Description | No composante | Fournisseur
Raspberry pi 4 4G | Raspberry Pi 4B/4GB ou 4B/4GB | Digikey
USB key | SFU3064GC2AE2TO-I-LF-1A1-STD | Digikey
GPS | Mosaic X5 / Piksi / Zed-F9P
Sonar | Imagenex 852 | Imaginex
Imu | BNO-055
DC to DC converter 5V | PYBE20-Q24-S5-T | Digikey
DC to DC converter 24V | PYBE20-Q24-S24-T | Digikey | Only for the Sonar *2
USB to RS-232 and RS485 | 15817 | waveshare
USB cable for the GPS | *1 | générique
USB cable for the serial converter | USB A-B | générique
Switch ON/OFF
Protection Diode | 6A10
*1 The USB connector may vary from one gps module to another.
*2 you can verify with Imagenex if your sonar is comptatible with 12v supply
if yes you can ommit the 24v suply

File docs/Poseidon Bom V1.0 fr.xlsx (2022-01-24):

Projet Hydro B
Description | No composante | Fournisseur
Raspberry pi 4 4G | Raspberry Pi 4B/4GB ou 4B/4GB | Digikey
clé usb | SFU3064GC2AE2TO-I-LF-1A1-STD | Digikey
GPS | Mosaic X5 / Piksi / Zed-F9P
Sonar | Imagenex 852 | Imaginex
Imu | BNO-055
Alimentation 5V | PYBE20-Q24-S5-T | Digikey
Alimentation 24V | PYBE20-Q24-S24-T | Digikey | Seulement pour le Sonar*2
Interface serie pour sonar | 15817 | waveshare
Cable USB pour le gps | *1 | générique
Cable USB pour le sonar | USB A-B | générique
Intérupteur on/off générique
Diode de protection 6A10
*1 le connecteur usb peut varier en fonction du model de gps.
Selon le modèle : USB micro-B (Piksi,Mosaic X5) , USB-C (Ublox ZED-F9P)
*2 a valider avec Imagenex si les nouveau sonar que vous avez peuvent fonctionner a 12v
si oui l'alimentation peut etre retirer.

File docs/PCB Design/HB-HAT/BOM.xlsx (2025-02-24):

C5380874 | Designator | Footprint | JLCPCB Part #（optional）
B550C | D2 | D_SMC | C134461
0.1uf /50v | C6 | C_1206_3216Metric | C841554
1k | R20,R3,R21,R4 | R_1206_3216Metric | C2889701
100r | R15,R12,R11 | R_1206_3216Metric | C17901
Battery_Cell | BT1 | BatteryHolder_Keystone_1058_1x2032 | C5470546
0.033R/2W | R10 | R_2512_6332Metric | C875726
1nf/2kv | C10 | C_1206_3216Metric | C9196
100uf/16v | C13 | CP_Elec_6.3x9.9 | C3151829
4.7uf/50v | C7,C8 | C_1206_3216Metric | C5448918
2A | F1 | Fuse_1206_3216Metric | C163126
2N7002 | Q2,Q3,Q1 | SOT-23 | C22446827
3.57k | R16 | R_1206_3216Metric | C2933682
INA238AIDGSR | U4 | SOP50P490X110-10N | C2868250
4.7k | R1,R2,R23,R22 | R_1206_3216Metric | C2907499
HIH8130-021-001 | IC1 | SOIC127P600X206-8N | C5380874
100nf | C12 | C_1206_3216Metric | C841554
DS3231MZ | U8 | SOIC-8_3.9x4.9mm_P1.27mm | C107410
2.2uH/4A | L1 | L_1210_3225Metric | C3002559
0.22uF | C19 | C_1206_3216Metric | C5448903
1.5K | R17 | R_1206_3216Metric | C5140814
100nF | C17 | C_1206_3216Metric | C841554

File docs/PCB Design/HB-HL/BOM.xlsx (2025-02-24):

Comment | Designator | Footprint | JLCPCB Part #（optional）
Conn_01x04_MountingPin | J2 | TE_84952-4_1x04-1MP_P1.0mm_Horizontal | C262731
80R | R3,R4 | R_1206_3216Metric | C270896
10pf | C1 | C_1206_3216Metric | C377016
150R | R2 | R_1206_3216Metric | C2907432
A3213LLHLT-T | U2 | SOT-23W | C75884
0.1uf | C2 | C_1206_3216Metric | C841554

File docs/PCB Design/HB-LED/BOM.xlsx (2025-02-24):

Comment | Designator | Footprint | JLCPCB Part #（optional）
Connector | J2 | SMD,P=1mm,Surface Mount，Right Angle | C262731

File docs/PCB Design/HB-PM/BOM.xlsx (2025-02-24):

Comment | Designator | Footprint | JLCPCB Part #（optional）
1uf | C1 | C_1206_3216Metric | C377070
1k | R2,R5,R3,R7,R1,R6,R4 | R_1206_3216Metric | C2889701
Fuse | F1 | Fuse_1206_3216Metric | C182308
DMP3010LK3Q-13 | Q2 | TO-252-2 | C461089
2N7002 | Q1,Q6,Q4,Q3,Q5 | SOT-23 | C22446827
0.1uf | C2 | C_1206_3216Metric | C841554
4.7k | R8 | R_1206_3216Metric | C2907499
ATtiny424-SS | U1 | SOIC-14_3.9x8.7mm_P1.27mm | C3234243

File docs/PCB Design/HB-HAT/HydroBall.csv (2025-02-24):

Id | Référence | Empreinte | Quantité | Désignation | Fournisseur et réf
1 | logo1,logo1 | logo cidco | 2 | LOGO
2 | D2 | D_SMC | 1 | B550C
3 | FID1,FID3,FID2,FID4,FID6,FID5 | Fiducial_0.75mm_Mask2.25mm | 6 | Fiducial
4 | C6 | C_1206_3216Metric | 1 | 0.1uf /50v
5 | U1 | zed-f9p | 1 | ~
6 | H4,H5,H3,H2,H6,H1 | MountingHole_2.7mm_M2.5_ISO7380_Pad | 6 | MountingHole
7 | R20,R3,R21,R4 | R_1206_3216Metric | 4 | 1k
8 | R15,R12,R11 | R_1206_3216Metric | 3 | 100r
9 | BT1 | BatteryHolder_Keystone_1058_1x2032 | 1 | Battery_Cell
10 | R10 | R_2512_6332Metric | 1 | 0.033R/2W
11 | C10 | C_1206_3216Metric | 1 | 1nf/2kv
12 | C13 | CP_Elec_6.3x9.9 | 1 | 100uf/16v
13 | C7,C8 | C_1206_3216Metric | 2 | 4.7uf/50v
14 | J14 | PinHeader_2x04_P2.54mm_Vertical | 1 | Conn_02x04_Counter_Clockwise
15 | J1 | JST_XH_B6B-XH-AM_1x06_P2.50mm_Vertical | 1 | Conn_01x05
16 | J11 | PinHeader_2x06_P2.54mm_Vertical | 1 | Conn_02x05_Top_Bottom
17 | J9 | PhoenixContact_MSTBVA_2,5_4-G-5,08_1x04_P5.08mm_Vertical | 1 | Conn_01x03
18 | F1 | Fuse_1206_3216Metric | 1 | 2A
19 | Q2,Q3,Q1 | SOT-23 | 3 | 2N7000
20 | J3,J6,J4,J7 | JST_XH_B5B-XH-AM_1x05_P2.50mm_Vertical | 4 | Conn_01x05
21 | R16 | R_1206_3216Metric | 1 | 3.57k
22 | U4 | SOP50P490X110-10N | 1 | INA238AIDGSR
23 | R1,R2,R23,R22 | R_1206_3216Metric | 4 | 4.7k
24 | IC1 | SOIC127P600X206-8N | 1 | HIH8130-021-001
25 | JP3,JP1 | SolderJumper-2_P1.3mm_Open_RoundedPad1.0x1.5mm | 2 | SolderJumper_2_Open
26 | J5 | JST_XH_B5B-XH-AM_1x05_P2.50mm_Vertical | 1 | Conn_01x06
27 | C12 | C_1206_3216Metric | 1 | 100nf
28 | J13 | JST_XH_B2B-XH-AM_1x02_P2.50mm_Vertical | 1 | Conn_01x06
29 | U8 | SOIC-8_3.9x4.9mm_P1.27mm | 1 | DS3231MZ
30 | L1 | L_1210_3225Metric | 1 | 2.2uH/4A
31 | C19 | C_1206_3216Metric | 1 | 0.22uF
32 | R17 | R_1206_3216Metric | 1 | 1.5K
33 | J2 | JST_XH_B7B-XH-AM_1x07_P2.50mm_Vertical | 1 | Conn_01x07
34 | U2 | bno055 | 1 | ~
35 | C17 | C_1206_3216Metric | 1 | 100nF
36 | C5,C9 | CP_Radial_D10.0mm_P5.00mm | 2 | 330uf/50v
37 | PS1 | CONV_PDQE20-Q24-S5-D | 1 | PDQE20-Q24-S5-D
38 | J8 | PinSocket_2x20_P2.54mm_Vertical | 1 | Raspberry_Pi_2_3

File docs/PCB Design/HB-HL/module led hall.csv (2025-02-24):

Id | Référence | Empreinte | Quantité | Désignation | Fournisseur et réf
1 | J1 | IDC-Header_2x03_P2.54mm_Vertical | 1 | Conn_02x03_Top_Bottom
2 | J2 | TE_84952-4_1x04-1MP_P1.0mm_Horizontal | 1 | Conn_01x04_MountingPin
3 | R3,R4 | R_1206_3216Metric | 2 | 80R
4 | C1 | C_1206_3216Metric | 1 | 10pf
5 | R2 | R_1206_3216Metric | 1 | 150R
6 | U2 | SOT-23W | 1 | A3213LLHLT-T
7 | C2 | C_1206_3216Metric | 1 | 0.1uf

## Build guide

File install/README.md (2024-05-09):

### Install instructions for Raspberry Pi:

Edit UBoot before running the install scripts:

When The RaspBerry Boot Press A Key On Your Keyboard.

Execute The Following Command

U-Boot> setenv bootdelay -2

U-Boot> saveenv

U-Boot> reset

----

execute the rscript acording to the material and os version

ubuntu 18 = melodic
ubuntu 20 = noetic

Rpi4 with ubuntu 20 server use rpi4-noetic.sh

### Automatic script launch upon new UP network interface

script example:

```
#!/bin/bash

IF=$1
STATUS=$2

if [ "$IF" == "wlan0" ]
then
    case "$2" in
        up)
        sh /opt/Poseidon/tools/CSB-User/upload_files_to_webserver.sh USER Directory2Transfer
        ;;
        down)
        #command 
        ;;
        *)
        ;;
    esac
fi

```
 
- put script in : /etc/NetworkManager/dispatcher.d/

- give execution right to script 
chmod +x script.sh

- sudo systemctl restart network-manager.service && sudo systemctl restart networking.service

- The RSA key for rsync connection needs be in root directory since dispatcher script are ran by root

---
### rsync passwordless connection
```
ssh-keygen
ssh-copy-id -i path/key.pub user@server
ssh user@server
logout
```

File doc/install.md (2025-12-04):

# Installation Guide (RPi4, Ubuntu 20.04, ROS Noetic)

## Prerequisites
- Hardware: Raspberry Pi 4 (4GB+ recommended)
- OS: Ubuntu 20.04 (64-bit)
- Network: Internet access for apt/rosdep
- Privileges: sudo

## One-shot install (recommended)
Use the bundled installer which chains all stage scripts:
```bash
sudo chown $USER:$USER /opt
cd /opt
git clone --recursive <repo-url> Poseidon
cd Poseidon
sh install/rpi4-noetic.sh <hotspot_if> <hotspot_ssid> <hotspot_pass> <wifi_if> <wifi_ssid> <wifi_pass> [rtc]
```
Examples:
- Software RTC: `sh install/rpi4-noetic.sh wlan1 Hydro-B cidco1234 wlan0 test pass-1234`
- Hardware RTC: append `rtc` as last arg.

What it does (in order):
1. `install/stages/1-base-ros-noetic.sh`
2. `install/stages/2-rpi4.sh <hotspot_if> <hotspot_ssid> <hotspot_pass> <wifi_if> <wifi_ssid> <wifi_pass>`
3. `install/stages/3-network.sh`
4. `install/stages/4-rpi.sh`
5. `install/stages/rtc.sh` (if `rtc` arg provided; otherwise still invoked as part of the script)
6. `install/stages/5-finalize.sh`
7. `install/stages/6-devices-rpi.sh`
8. `install/stages/build-rpi4.sh`

At the end, reboot is recommended.

## Manual steps (if you cannot run the installer)
1) Base packages:
```bash
sudo apt-get update
sudo apt-get install -y build-essential ccache cmake git pkg-config curl wget ca-certificates python3 python3-pip python3-venv python3-rosdep
sudo apt-get install -y libssl-dev libboost-system-dev libopencv-dev libpcl-dev libwebsocketpp-dev rapidjson-dev libgps-dev libexiv2-dev libxml2-dev libxslt1-dev libyaml-cpp-dev
```
2) ROS Noetic:
```bash
sudo sh -c 'echo "deb http://packages.ros.org/ros/ubuntu $(lsb_release -sc) main" > /etc/apt/sources.list.d/ros-latest.list'
curl -s https://raw.githubusercontent.com/ros/rosdistro/master/ros.asc | sudo apt-key add -
sudo apt-get update
sudo apt-get install -y ros-noetic-desktop-full
echo "source /opt/ros/noetic/setup.bash" >> ~/.bashrc
source /opt/ros/noetic/setup.bash
sudo rosdep init || true
rosdep update
```
3) Clone Poseidon:
```bash
sudo chown $USER:$USER /opt
cd /opt
git clone --recursive <repo-url> Poseidon
cd Poseidon
```
4) Stage scripts (mirroring the installer):
```bash
sh install/stages/1-base-ros-noetic.sh
sh install/stages/2-rpi4.sh <hotspot_if> <hotspot_ssid> <hotspot_pass> <wifi_if> <wifi_ssid> <wifi_pass>
sh install/stages/3-network.sh
sh install/stages/4-rpi.sh
sh install/stages/rtc.sh   # include only if hardware RTC is present
sh install/stages/5-finalize.sh
sh install/stages/6-devices-rpi.sh
sh install/stages/build-rpi4.sh
```
5) Build workspace:
```bash
cd /opt/Poseidon/src/workspace
catkin_make -j1 -DCATKIN_BLACKLIST_PACKAGES="mavros;inertial_sense;velodyne;ins_piksi;velodyne_pointcloud;velodyne_driver;velodyne_laserscan;gnss_mosaic_x5;tf"
source devel/setup.bash
```
6) Run simulator:
```bash
roslaunch launch/Simulator/dummy_simulator_virtual-machine.launch
```
Then browse to `http://localhost`.

7) Tests:
- C++/Python/ROS: `catkin_make run_tests -j1 -DCATKIN_BLACKLIST_PACKAGES="ins_piksi;libmavconn;echoboat_odometry;mavros_msgs;mavros;mavros_extras;test_mavros;gnss_mosaic_x5;imu_bno055;sonar_imagenex852;inertial_sense;raspberrypi_vitals;imu_null;sonar_dummy;gnss_dummy;lidar_filtering"`
- JS: `cd /opt/Poseidon/www/webroot/js && npm test --coverage`

## Notes
- `install/rpi4-noetic.sh` orchestrates all stage scripts; prefer it when possible.
- Keep `doc/` Markdown as the source of truth; PDF generation can be added later via CI.

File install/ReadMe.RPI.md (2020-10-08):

Before Runing Any Script You Have To Edit Uboot.

When The RaspBerry Boot Press A Key On Your Keyboard.

Execute The Following Command

U-Boot> setenv bootdelay -2

U-Boot> saveenv

U-Boot> reset

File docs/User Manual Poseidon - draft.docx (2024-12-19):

Poseidon

User Manual

CIDCO

D.D. 2024-12-02

## Index

Index 3

System Requirements 4

Connection Instructions (WiFi) 5

Web Interface - (ROS core not launched) [Yellow card] 6

Web Interface - (System not ready)[Red card] 7

Web Interface - (System ready)[Green card] 8

Web Interface - (Record) 9

Web Interface - (System Status) 10

Web Interface - (Download dataset) 11

Web Interface - (Automatic IMU calibration) 12

Web Interface - (Manual IMu and Sonar calibration) 13

Connection block diagram 14

Wiring Diagram 15

## System Requirements

Power : 12Vdc from a 12V battery or a 12V psu.

Never apply power on the system if the GNSS antenna and/or the Sonar is not connected!

## Connection Instructions (WiFi)

First step : Connect to the Hydro B wifi network. The password to connect is : cidco1234

Second step : Open a web browser and type 192.168.1.1

## Web Interface - (ROS core not launched) [Yellow card]

If ROS is not launched, the web page will look like this.

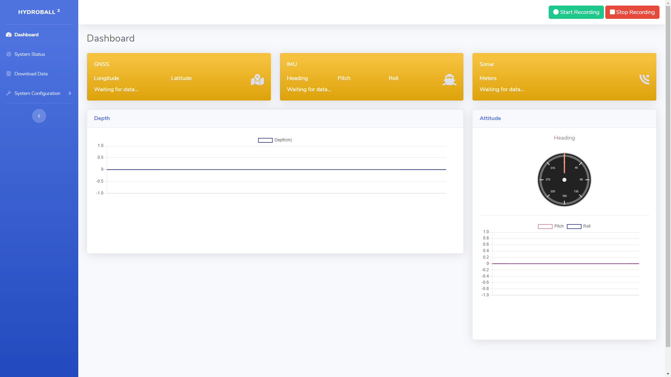
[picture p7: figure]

## Web Interface - (System not ready)[Red card]

If the system is not ready one of the three cards (NDSS, IMU, Sonar) will be red.

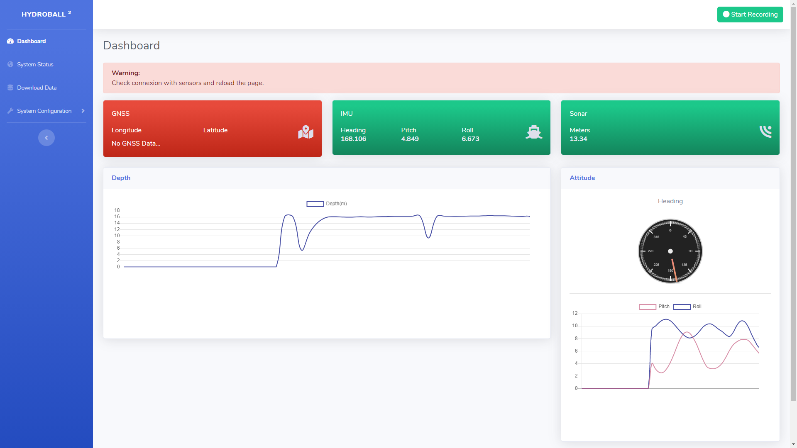
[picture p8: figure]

GNSS (red) - You have to wait a few minutes until the GNSS obtain the 3D fix. ...

IMU (red) - ...

Sonar (red) - ...

## Web Interface - (System ready)[Green card]

When the system is ready the three cards will be green.

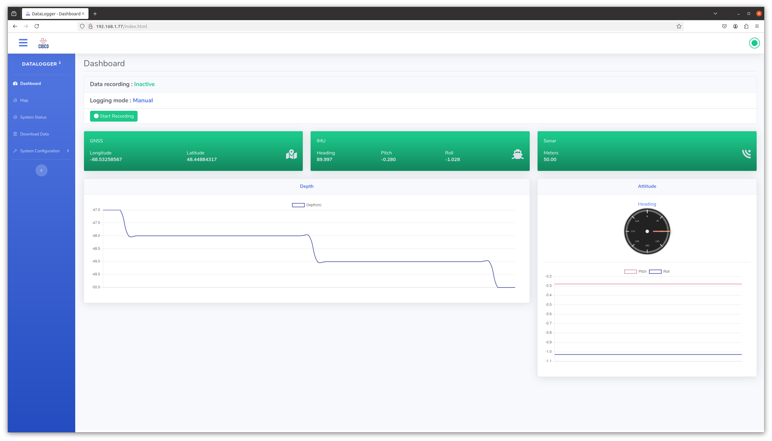
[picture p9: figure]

At this time you can start recording by pressing the green [Start Recording] button.

GNSS value : Decimal degrees

IMU value : Decimal degrees

Positioning convention : ENU

## Web Interface - (Record)

Data recording is in progress.

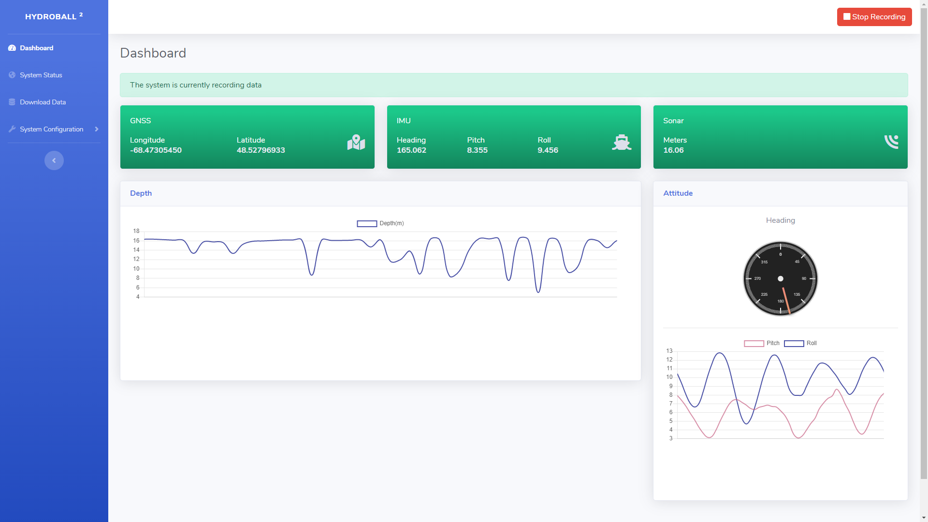
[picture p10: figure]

The system informs you that the recording is started in two ways.

The green button [Start Recording] toggle to red [Stop Recording]

A banner show [The system is currently recording data]

Note: The recording of RAW gps data begins when the system is powered on and stops only when the system is switched off.

## Web Interface - (System Status)

You can see the system status on the System Status page.

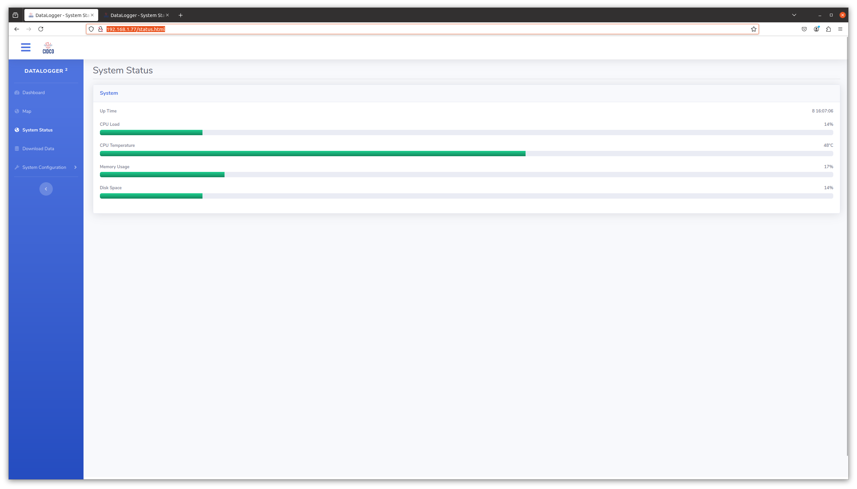
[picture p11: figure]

(System Status on Gen. A)


(System Status on Gen. B)

In this page you can monitor the state of the system.

CPU Load

CPU Temperature

Memory Utilization

Disk Space

## Web Interface - (Download dataset)

You can download the dataset and RAW gps data from the Download Data page

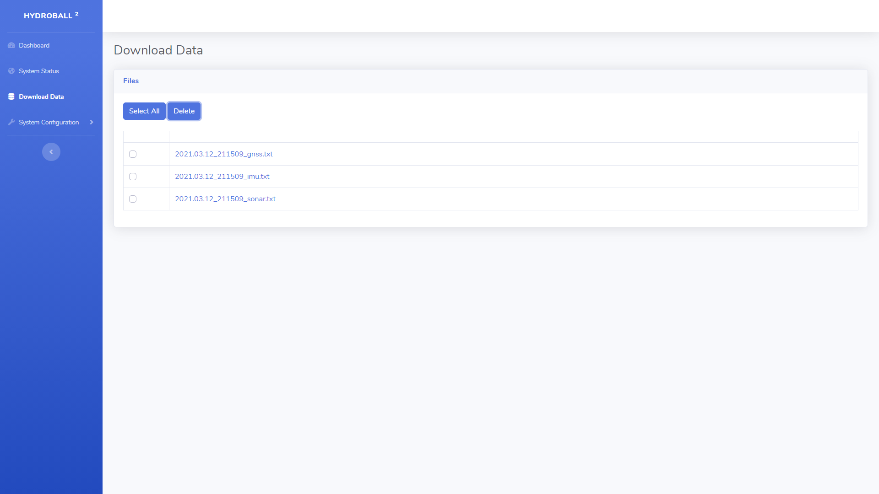
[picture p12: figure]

You can download each file by clicking on their name.

You can select the deleted files with the checkboxes or use the [Select All] button. When you press the [Delete] button a modal window will prompt you to confirm the deletion of the selected files.

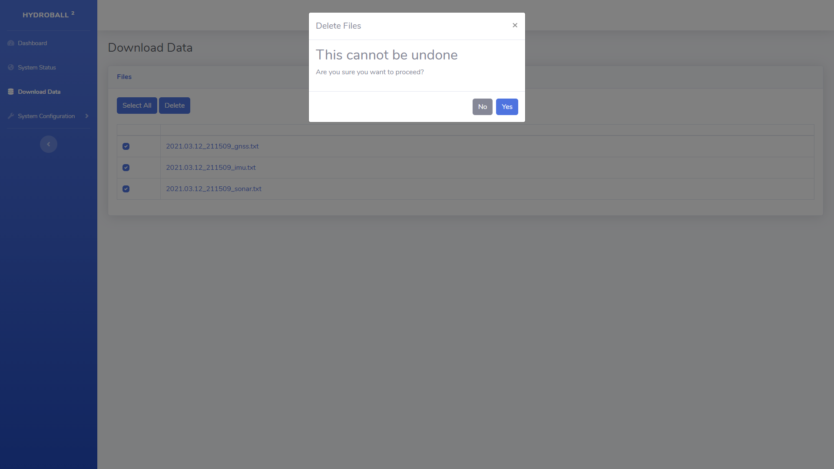
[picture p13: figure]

## Web Interface - (Automatic IMU calibration)

This page is used to launch the automatic calibration procedure of the IMU

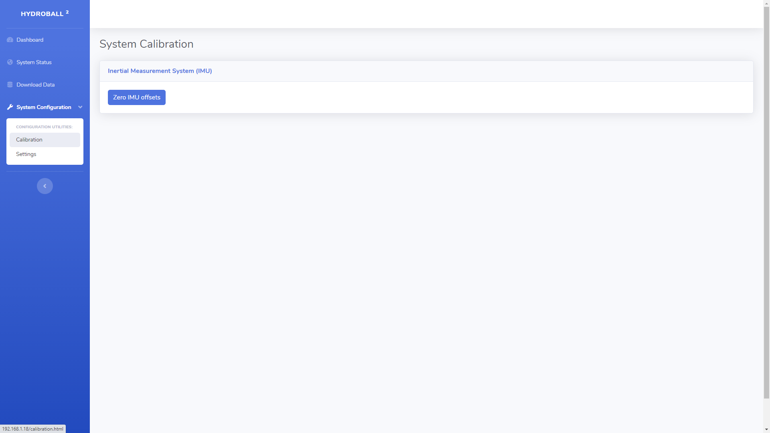
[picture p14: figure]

## Web Interface - (Manual IMu and Sonar calibration)

This page allows you to manually calibrate the IMU and Sonar.


IMU Setting

Heading Offset value : Decimal degrees

Pitch Offset value : Decimal degrees

Roll Offset value : Decimal degrees

Imagenex Setting
Sonar Absorption value : /10dB/M @ 675kHz

Sonar Pulse Length value : microseconds

Sonar Range value : Meters

Sonar Start Gain value : dB

Sonar range should be 5,10,20,30,40 or 50 Meters

CSB Integration

Api Key : 64 char from CSB server

Api Port : 433 or 80

Api Server : csb.cidco.ca

Api Url Path : /CSBWeb/JobServlet

Geo Fence : could be WKT polygon or multipolygon

default : MULTIPOLYGON (((-180 -90, -180 90, 180 90, 180 -90, -180 -90)))

The geofence function will stop the loggin of the sonar when you are outside of the polygon. The other data will be logged (GNSS, IMU, Vitals ...)

Hotspot SSID : SSID of the hydroblock/hydroball : default = HydroB

Log Rotation Interval :Delay for the log rotation in seconds : default = 3600 (1h)

Sonar Serial Baud Rate : Serial baudrate for the sonar interface : Default 9600

usual value 4800, 9600, 33600,115200

Speed Threshold : Speed Threshold to start and stop the loging : default 6 kmh
ex : start the record when the speed is over 6kmh and stop under 6kmh

(The function will be deprecated)

If the device is equiped of an wifi module for automatic files transfert.

Wifi SSID : SSID of your wifi network

Wifi Password : Password of your wifi

Wifi Transfer Enable : true to enable the files transfert when the wifi is detected.

Logging Mode :

manual : you have to manualy start and stop the logging from the dashboard

speed : the logging will start when the device will move faster than the value of Speed Threshold filed.

always : the logging will start automaticly at boot of the device.

## Connection block diagram

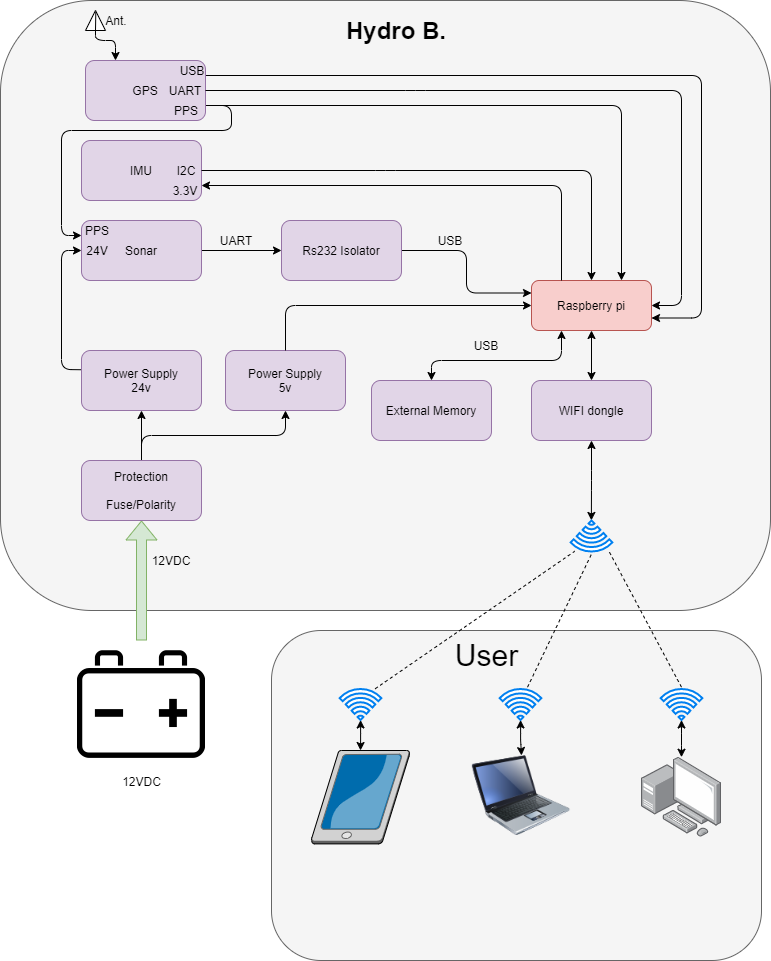
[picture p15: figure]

## Wiring Diagram

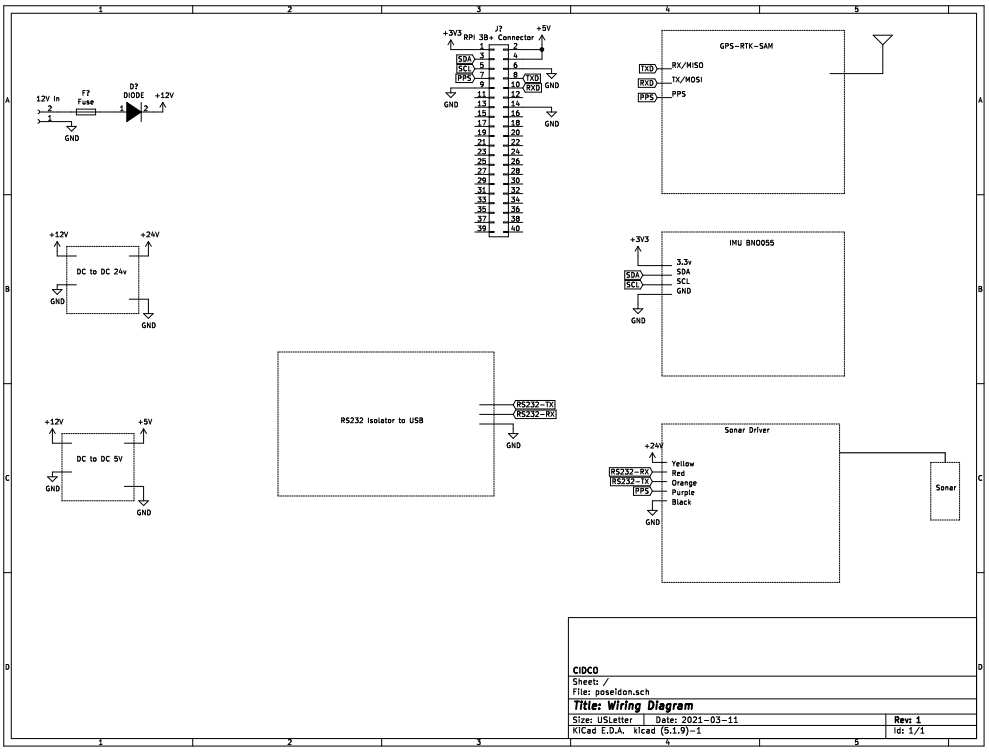
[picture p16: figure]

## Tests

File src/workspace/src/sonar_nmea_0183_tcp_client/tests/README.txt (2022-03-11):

make sure /home/ubuntu/Poseidon/www/webroot/record/ is created or whatever the path is in the launch file

sudo apt install socat

nmea_device_node listen on /dev/sonar by default
$sudo ln -s /home/ubuntu/sonar /dev/sonar
$sudo ln -s /dev/pts/0 /home/ubuntu/sonar
$sudo chown -h :dialout /dev/sonar

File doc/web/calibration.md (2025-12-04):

# calibration.html

## Overview
- Calibration utility page (currently limited to IMU zeroing).
- Uses the config WebSocket (`hydroball_config_websocket_node`, `ws://<host>:9004`) to send commands.

## Actions / Commands
- “Zero IMU offsets” button calls `sendZeroImu()` → sends `{"command":"zeroImu"}` over the WebSocket.
- No other UI fields; no feedback is displayed by default (socket `onmessage` is a no-op).

## Data Source
- WebSocket: `ws://<host>:9004` (shared with settings/config). No authentication.
- Incoming messages are parsed but ignored (`processState` is empty); extend if server emits acknowledgements.

## Scripts
- `js/calibrationScript.js`: opens WebSocket, defines `sendZeroImu`, placeholder `processState`.
- Shared includes: `js/script.js`, `js/poseidon.js`, SB Admin 2 assets.

## Notes / Caveats
- No confirmation or status is shown; users must verify IMU behavior separately.
- Add server-side support and UI feedback if more calibration flows are introduced.

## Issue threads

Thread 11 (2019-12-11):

Intégrer IMU HG1120 dans ROS

glabmoris, 2019-12-11:

glabmoris, 2024-10-21:
IMU is deemed too expensive for the HB.

Performance seems good though.

Closing the issue.

Closed 2024-10-21.

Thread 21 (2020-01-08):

[Hardware] MUX NMEA0183

Ddoiron-cidco, 2020-01-08:
voici une solution qui pourais regler notre probleme de latency.

https://www.yachtd.com/products/multiplexer.html

c'Est un multiplexeur pour du nmea 5 entré sortie nmea0183 et un port Seatalk

Cela permeterais d'avoir sur le port série matériel du raspberry 4 équipement nmea0183

glabmoris, 2024-10-21:
Closed due to inactivity

Closed 2024-10-21.

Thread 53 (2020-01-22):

[Hardware] Integrer gps Hemisphere

Ddoiron-cidco, 2020-01-22:
on ne peut ouvrir l'interface série car elle est ouverte par gpsd.

il faudrais arreter le service suivit de l'ouverture du port série pour transmetre la configuration pour relancer le service pgsd

Closed 2024-10-21.

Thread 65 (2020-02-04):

Deconnection sonar

Ddoiron-cidco, 2020-02-04:
si la communication du sonard est couper l'interface web est pas aviser et la donnée est rafraichie avec la meme valeur pour l'éternité

glabmoris, 2024-10-21:
Implementing this would require hypotheses based on sonar data rate, which is vendor specific. Closing issue in the spirit of vendor agnostic implementation.

Closed 2024-10-21.

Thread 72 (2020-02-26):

[Catarob]lidar

Ddoiron-cidco, 2020-02-26:
https://www.dfrobot.com/product-1773.html

Ddoiron-cidco, 2023-09-13:
replaced by VLP16

Closed 2023-09-13.

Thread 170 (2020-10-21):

[inertial_sense] Make unit tests

glabmoris, 2020-10-21:
Make a unit test that ensures proper data is coming through the imu topic

glabmoris, 2024-10-21:
Dropping support for inertial sense INS

closing issue

Closed 2024-10-21.

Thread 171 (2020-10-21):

[sonar_imagenex852] Add Unit tests

glabmoris, 2020-10-21:
Make a unit test that ensurs proper data is going to/from the sonar.

glabmoris, 2024-10-21:
Now part of diagnostics.

closing issue

Closed 2024-10-21.

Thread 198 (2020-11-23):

Support for magnetic declination correction from a model

PMNDI3, 2020-11-23:
True North used in geodesy can be calculated with NRCAN or NOAA applications. Here are the useful links:
https://geomag.nrcan.gc.ca/calc/mdcal-fr.php
https://www.ngdc.noaa.gov/geomag/calculators/magcalc.shtml
TrueNorth=NorthMag-Declination

This fix is appropriate to avoid handling errors in datagrams when importing into caris for processing= problem currently encountered.

glabmoris, 2024-10-21:
Handled in post-processing.

closing issue

Closed 2024-10-21.

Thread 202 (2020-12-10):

imu bno055 calibration error

Ddoiron-cidco, 2020-12-10:
error with the calibration files

the files is generate with bad chmod
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

causing error on recalibration
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

glabmoris, 2024-10-21:
Fixed

Closed 2024-10-21.

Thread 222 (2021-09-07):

Intégration Piksy Micro - GPS

glabmoris, 2021-09-07:
Selon le même modèle que le module de node F9P, lire les datagramme SBP sur le port USB du GPS et les logger dans un fichier binaire. Contrairement au node F9P, il est important de lire datagramme par datagramme (et non octet par octet) car un traitement ultérieur sera fait sur les datagrammes concernant l'IMU interne.

Closed 2021-11-11.

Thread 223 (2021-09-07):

Intégration Septentrio Mosaic X5

glabmoris, 2021-09-07:
Selon le même pattern que le module Ublox F9P, lire les données binaires du module via USB et les logger dans un fichier binaire.

JordanMcManus, 2021-09-30:
Mosaic-X5 sur le pickup:

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

Closed 2021-11-10.

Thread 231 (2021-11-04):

[To Fix] IMU dummy

Ddoiron-cidco, 2021-11-04:
Imu dummy is publishing in the topic /odom type nav_msfs/Odometry and should be /imu/data typer sensor_msg/Imu

Closed 2021-11-10.

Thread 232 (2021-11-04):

[To Fix]gnss dummuy

Ddoiron-cidco, 2021-11-04:
in the dummy the status is set to 0 and in the web socket the data is not trasmited if the status is 0

`if( !state.position.header.seq  &&  state.position.status.status < 0) {
            //No fix
            rapidjson::Value positionArray(rapidjson::Type::kArrayType);
            telemetry.AddMember("position", positionArray, telemetry.GetAllocator()); // empty position array
`

Closed 2021-11-10.

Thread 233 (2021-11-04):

[To Fix] hydroball_data_websocket

Ddoiron-cidco, 2021-11-04:
The function stateChanged look for the IMU msg un the state msg.
if the imu is not presnt no data is display on the web interface.

`void stateChanged(const state_controller_msg::State & state) {
        uint64_t timestamp = (state.imu.header.stamp.sec * 1000000) + (state.imu.header.stamp.nsec/1000);
        //TODO: maybe add our own header?
        if(timestamp - lastTimestamp > 200000){
            std::string jsonString;
            convertState2json(state, jsonString);

            std::lock_guard<std::mutex> lock(mtx);
            for (auto it : connections) {
                 srv.send(it,jsonString,websocketpp::frame::opcode::text);
            }

            lastTimestamp = timestamp;
        }
    }
`

Closed 2021-11-09.

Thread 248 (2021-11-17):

[sonar_nmea-0183_tcp_client] Add use* parameters

glabmoris, 2021-11-17:
Add the following (boolean) parameters to both the DeviceNmeaClient and NetworkNmeaClient constructors:

useSonar
useGnss
useAttitude

By default, only useSonar should be true, the others  (useGnss, useAttitude) should be false.

patcmorneau, 2021-11-17:
je suis pas sur de bien comprendre, il me semble que c'est déjà comme ça mais avec des nom de variable différent
```

		bool useDepth = true;
		bool usePosition = false;
		bool useAttitude = false;
```

pour faire mes tests j'utilisais le stack : hydrobox_nmeadevice.lauch et j'enlevais les nodes rasberry_vitals et gnss_mosaic.
Si je veux tester ma condition de logging, quelle node suis-je le mieux d'utiliser ?

glabmoris, 2021-11-17:
Le nmea_device_node est le mieux. Par paramètres, on parle de paramètres ROS (via getParam). Les paramètres extraits avec getParam vont venir populer les variables:

bool useXXX = ros::getParam(....);

patcmorneau, 2021-11-17:
comment que je fais pour populer : bootstrappedGnssTime
c'est la variable qui me manque pour confirmer ou non que ca fonctionne
```
bool Writer::toggleLogging(logger_service::ToggleLogging::Request & request,logger_service::ToggleLogging::Response & response){
	mtx.lock();

	if(bootstrappedGnssTime){
		std::cerr<<" Gnss ok \n";
		if(!loggerEnabled && request.loggingEnabled){
			//Enabling logging, init logfiles
			loggerEnabled=true;
			init();
		}
```
les parametres sont passés comme il faut

```
PARAMETERS
 * /Sonar/usePosition: True
 * /logger_text/speed_threshold: 1.0
```

glabmoris, 2021-11-17:
It's done automatically through gnssCallback defined in src/logger_text.cpp (line 64):

```
void Writer::gnssCallback(const sensor_msgs::NavSatFix& gnss){

	if(!bootstrappedGnssTime && gnss.status.status >= 0){
		bootstrappedGnssTime = true;
	}

	if(bootstrappedGnssTime && loggerEnabled){
        (...)
```

It's registered in the main in nodes/logger_text_node.cpp (line 22):

```
ros::Subscriber sub1 = n.subscribe("fix", 1000, &Writer::gnssCallback,&writer);
```

glabmoris, 2021-11-22:
Clo

Closed 2021-11-22.

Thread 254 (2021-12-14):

[Boot USB]

Ddoiron-cidco, 2021-12-14:
Boot raspberry pi 4 with USB stick or ssd

Ddoiron-cidco, 2021-12-14:
Modify the boot sequence in the eeprom of the raspberry

https://www.zdnet.com/article/booting-my-raspberry-pi-4-from-a-usb-device/

Ddoiron-cidco, 2021-12-14:
fix the boot for ubuntu 20

https://jamesachambers.com/raspberry-pi-4-ubuntu-20-04-usb-mass-storage-boot-guide/

Ddoiron-cidco, 2021-12-14:
Fix for the USB driver

https://forums.raspberrypi.com/viewtopic.php?f=28&t=245931

Ddoiron-cidco, 2021-12-14:
USB3 Kingston Datatravler  100 G3  > slow speed in usb2 /usb3 with or whitout the fix
USB2 NXT usb drive > same speed than the Kingston Datatravler

Ddoiron-cidco, 2021-12-14:
Ubuntu 21 support auto usb boot but somme apps dont work in ubuntu 21

* RPi.GPIO
* Wiring Pi
* ROS

Ddoiron-cidco, 2021-12-14:
We have to work with ubuntu 20 and implement the boot / firmware update script

Ddoiron-cidco, 2021-12-15:
I got Swiisspib usb stick today and the installation process is 3 to 4 rime faster than the SD card

Ddoiron-cidco, 2022-01-12:
Installation is working on RPI4 and swiisbid usp stick

Closed 2022-01-12.

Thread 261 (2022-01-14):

Logging Modes

glabmoris, 2022-01-14:
Support 3 loggin modes:

- Manual: We toggle logging on/off
- Speed-based : We trigger logging on/off with speed
- Always On:  we are always on

Ddoiron-cidco, 2022-01-14:
`<div class="dropdown no-arrow mb-4">
<button class="btn btn-secondary dropdown-toggle" type="button" id="dropdownMenuButton" data-toggle="dropdown" aria-haspopup="true" aria-expanded="false"> Dropdown (no arrow) </button>
	<div class="dropdown-menu" aria-labelledby="dropdownMenuButton">
		<a class="dropdown-item" href="#">Action</a>
        <a class="dropdown-item" href="#">Another action</a>
        <a class="dropdown-item" href="#">Something else here</a>
    </div>
</div>`

glabmoris, 2022-01-17:
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

The problem with the dropdown button widget is that it doesn't disply the currently selected item. It's good to pack a lot of action links into a single dropdown, but doesn't do wso as efficiently as a good old <select>

patcmorneau, 2022-01-17:
je ne sais pas si c'est toujours a jour ca mais maintenant le code
ressemble plus a ca et le mode sélectioné vient du config file...

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
Par Contre il y a un problème intermittent ... le fichier config.txt n'est
pas lu correctement ou le problème est ailleurs(race condition) mais des
fois quand je lance roslaunch ca me fait ca (pas souvent):

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

Le lun. 17 janv. 2022 à 10:42, Guillaume Morissette <
***@***.***> a écrit :

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

patcmorneau, 2022-03-09:
can be close

Ddoiron-cidco, 2022-05-27:
@glabmoris  to be close

glabmoris, 2024-10-21:
Fixed.

Closed 2024-10-21.

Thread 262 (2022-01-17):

Rpi slow and unable to connect in ssh or ping local network

Ddoiron-cidco, 2022-01-17:
If the local network and the wifi is in the same network 192.168.1.* the raspberry become slow and the nerwork interface fail to respond.

To fix it we have ton change the ip configuration on ethernet or wifi.

we should change the ip range for the wifi for someting in the midle of the range like 192.168.100.*

Closed 2022-01-24.

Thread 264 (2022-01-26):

Améliorer robustesse mémoire flash

tomypineau, 2022-01-26:
En général les carte SD sont designées pour rouler un OS (plusieurs écritures dans le même secteur) alors que les clés USB sont utilisées pour du stockage (plusieurs écritures dans des secteurs différents). Il est donc possible d'obtenir des cartes SD spécialisées qui permettent beaucoup plus d'écriture dans le même secteur (60000 vs 3000 pour la flash) avant corruption. Cela n'existe pas au niveau USB. Les USB "industriel" vont souvent garantir la rapididé, mais ne seront pas beaucoup supérieur en terme de corruption.

Il pourrait donc être intéressant de bouger la section OS vers une carte SD et si c'est possible, mettre cette partition en lecture seul. Le data quant à lui pourrait être sur le USB sans trop de problèmes.

https://www.ni.com/en-ca/support/documentation/supplemental/12/understanding-life-expectancy-of-flash-storage.html
https://www.embeddedts.com/assets/preventing-filesystem-corruption-in-embedded-linux

glabmoris, 2022-01-27:
Merci Tomy,

Ce sont des points pertinents. Je déclinerais ce dernier en les questions suivantes:

 - Est-on en mesure de quantifier la différence de vulnérabilité à la corruption des deux solutions? Le systeme peut facilement supporter l'une ou l'autre des options.

 - As-tu des suggestions de cartes SD qui seraient plus robustes que la SwissBit proposée (https://www.digikey.ca/en/products/detail/swissbit/SFU3064GC2AE2TO-I-LF-1A1-STD/12181130)? Un de ses features clé est la feature hotplug sans corruption, ce qui n'est pas le cas des cartes SD qui ont une fenêtre d'opportunité de corruption par design lors d'une coupure de courant au milieu d'un cycle de lecture/écriture. Car au delà des comparatifs sur l'endurance de la mémoire NAND utilisée, c'est surtout le fait qu'on ne peut pas contrôler quand l'alimentation sera coupée qui pose le risque de corruption le plus grand si on considère que l'appareil peut être utilisé dans tous genres d'embarcations (...à mon avis...ça serait intéressant d'en discuter).

 - L'option d'une partition en lecture seule est définitivement une amélioration intéressante. Cependant, ceci exige le maintien d'une configuration d'Ubuntu sur mesure, ainsi que de doubler les coûts des appareils de stockage.  Je crée un issue à cet effet, le #268

glabmoris, 2024-10-21:
Fixed

Closed 2024-10-21.

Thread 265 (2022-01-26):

Ajout d'un RTC

tomypineau, 2022-01-26:
Pour que le système puisse avoir une base de temps si le signal GPS n'est pas fonctionnel.

Nous avons déjà utilisé un DS3231MZ avec un pi qui fonctionnait bien.

glabmoris, 2022-01-28:
C'est un ajout intéressant, il faudrait ajouter de la logique autour de chrony pour inclure la synchro de la RTC au temps satellite (via rtcsync) et l'inverse (RTC vers sysclock) lorsqu'on n'a pas de fix GPS/PPS et que l'horloge système n'est pas à l'heure (car si on fait juste perdre le fix GPS, l'horloge systeme continue de fonctionner, seulement avec des risques de drift).

Ddoiron-cidco, 2022-02-23:
Test with GPS stream cut

before disconnecting the antenna
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

during the antenna disconected
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

when reconnecting the antenna
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

the gps is in fix 3D
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

after 1 min
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

after 5 min
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

glabmoris, 2022-02-23:
Done in #278

Closed 2022-02-23.

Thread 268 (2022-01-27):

Dedicated read-only OS partition

glabmoris, 2022-01-27:
(Spinoff from #264)

Significant improvements on stability could be made by using a dedicated read-only partition/storage device for the OS install.

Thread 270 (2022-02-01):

echoboat odometry

patcmorneau, 2022-02-01:
missing sbg driver dir

Closed 2022-02-01.

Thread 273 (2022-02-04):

gnss fix does not get updated

patcmorneau, 2022-02-04:
when starting the raspberrypi it launch poseidon but gps fix is not there yet and does not get updated after

glabmoris, 2022-02-04:
Can you explain the problem a bit more in detail?

Do you get a fix and it doesn't get updated?

patcmorneau, 2022-02-04:
thats right, once i see that the rpi date is sync with the gps i have to restart the poseidon stack... happened with the zf9p

patcmorneau, 2022-02-16:
[rosmaster.master][INFO] 2022-02-16 14:58:08,977: -SERVICE [/state_controller/get_loggers] /state_controller rosrpc://ubuntu:52793
[rosmaster.threadpool][ERROR] 2022-02-16 14:58:08,979: Traceback (most recent call last):
  File "/opt/ros/noetic/lib/python3/dist-packages/rosmaster/threadpool.py", line 218, in run
    result = cmd(*args)
  File "/opt/ros/noetic/lib/python3/dist-packages/rosmaster/master_api.py", line 210, in publisher_update_task
    ret = xmlrpcapi(api).publisherUpdate('/master', topic, pub_uris)
  File "/usr/lib/python3.8/xmlrpc/client.py", line 1109, in __call__
    return self.__send(self.__name, args)
  File "/usr/lib/python3.8/xmlrpc/client.py", line 1450, in __request
    response = self.__transport.request(
  File "/usr/lib/python3.8/xmlrpc/client.py", line 1153, in request
    return self.single_request(host, handler, request_body, verbose)
  File "/usr/lib/python3.8/xmlrpc/client.py", line 1169, in single_request
    return self.parse_response(resp)
  File "/usr/lib/python3.8/xmlrpc/client.py", line 1341, in parse_response
    return u.close()
  File "/usr/lib/python3.8/xmlrpc/client.py", line 655, in close
    raise Fault(**self._stack[0])
xmlrpc.client.Fault: <Fault -1: 'publisherUpdate: unknown method name'>

patcmorneau, 2022-02-16:
i think the problem is in the gpsd_client package
with command cgps the status is 2
but in gpsd_client/src/client.cpp line 266 -> fix.status.status is empty (no status)
i believe theres something wrong with the switch case at line 231 in client.cpp

gpsd installed vesion:
gpsd is already the newest version (3.20-8ubuntu0.4).

```

      /* gpsmm pollutes the global namespace with STATUS_,
       * so we need to use the ROS message's integer values
       * for status.status
       */
      switch (p->status) {
        case STATUS_NO_FIX:
          fix->status.status = -1; // NavSatStatus::STATUS_NO_FIX;
          break;
        case STATUS_FIX:
          fix->status.status = 0; // NavSatStatus::STATUS_FIX;
          break;
// STATUS_DGPS_FIX was removed in API version 6 but re-added afterward
#if GPSD_API_MAJOR_VERSION != 6
        case STATUS_DGPS_FIX:
          fix->status.status = 2; // NavSatStatus::STATUS_GBAS_FIX;
          break;
#endif
      }

      fix->status.service = NavSatStatus::SERVICE_GPS;

      fix->latitude = p->fix.latitude;
      fix->longitude = p->fix.longitude;
      fix->altitude = p->fix.altitude;

      /* gpsd reports status=OK even when there is no current fix,
       * as long as there has been a fix previously. Throw out these
       * fake results, which have NaN variance
       */
      if (std::isnan(p->fix.epx) && check_fix_by_variance) {
        return;
      }

      fix->position_covariance[0] = p->fix.epx;
      fix->position_covariance[4] = p->fix.epy;
      fix->position_covariance[8] = p->fix.epv;

      fix->position_covariance_type = NavSatFix::COVARIANCE_TYPE_DIAGONAL_KNOWN;

      navsat_fix_pub.publish(fix);
      ROS_INFO_STREAM("gpsd_client, fix status : " << fix->status.status);
    }
```

patcmorneau, 2022-02-17:
gnss callback in logger text does not get called and cannot update bootstrapGnssTime, without gnss fix we cannot toggle the logging.

the reason why its not getting called : xmlrpc.client.Fault: <Fault -1: 'publisherUpdate: unknown method name'>
```
[rosmaster.master][INFO] 2022-02-17 16:54:20,147: publisherUpdate[/fix] -> http://ubuntu:36719/ []: sec=0.01, exception=<Fault -1: 'publisherUpdate: unknown method name'>
[rosmaster.threadpool][ERROR] 2022-02-17 16:54:20,148: Traceback (most recent call last):
  File "/opt/ros/noetic/lib/python3/dist-packages/rosmaster/threadpool.py", line 218, in run
    result = cmd(*args)
  File "/opt/ros/noetic/lib/python3/dist-packages/rosmaster/master_api.py", line 210, in publisher_update_task
    ret = xmlrpcapi(api).publisherUpdate('/master', topic, pub_uris)
  File "/usr/lib/python3.8/xmlrpc/client.py", line 1109, in __call__
    return self.__send(self.__name, args)
  File "/usr/lib/python3.8/xmlrpc/client.py", line 1450, in __request
    response = self.__transport.request(
  File "/usr/lib/python3.8/xmlrpc/client.py", line 1153, in request
    return self.single_request(host, handler, request_body, verbose)
  File "/usr/lib/python3.8/xmlrpc/client.py", line 1169, in single_request
    return self.parse_response(resp)
  File "/usr/lib/python3.8/xmlrpc/client.py", line 1341, in parse_response
    return u.close()
  File "/usr/lib/python3.8/xmlrpc/client.py", line 655, in close
    raise Fault(**self._stack[0])
xmlrpc.client.Fault: <Fault -1: 'publisherUpdate: unknown method name'>
```
possible explanation :
https://github.com/ros/ros_comm/issues/572#issuecomment-89087064

Closed 2022-02-18.

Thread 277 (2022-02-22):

[install/stages/1-base-ros-*.sh] Convert script to Submodules

Ddoiron-cidco, 2022-02-22:
echo "cleaning gpsd_client"
sudo rm -rd /home/ubuntu/Poseidon/src/workspace/src/gpsd_client
sudo rm -rd /home/ubuntu/Poseidon/src/workspace/src/gps_umd
sudo rm -rd /home/ubuntu/Poseidon/src/workspace/src/gps_common

echo "Downloading GPSD-Client"
cd /home/ubuntu
git clone https://github.com/swri-robotics/gps_umd.git
cd /home/ubuntu/gps_umd
sudo mv gps* /home/ubuntu/Poseidon/src/workspace/src/
cd /home/ubuntu
sudo rm -rd gps_umd

glabmoris, 2024-10-21:
Managed in install script.

Closing issue

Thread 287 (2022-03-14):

Loging mode

Ddoiron-cidco, 2022-03-14:
after reboot of the system the loger start in alwais on but the setting is set to speed based

i set the value and save the setting and all is ok on the dashboard
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

after reboot the dashboard indicate
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

the setting is
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

when i manualy start ros i get t'hit message.
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

Closed 2022-05-27.

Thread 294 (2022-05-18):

[GNSS-ZED-F9P node] error in ubx files generation

Ddoiron-cidco, 2022-05-18:
Acording to the configuration of the gnss the rawx and sfrbx are transmited on the usb port
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

The ubx file cant be converted by rtkconv
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

glabmoris, 2022-05-18:
That's a great find, it's clearly byte-ordering error, probably from developing on x86_64 (little-endian) to run on ARM (big-endian)

patcmorneau, 2022-05-18:
Thanks for the great documentation on the bug, working on it ASAP.

patcmorneau, 2022-05-19:
ubx file are now readablewith this fix:
L.211 -> gnss_zed_f9p.h
```
//write frame to bin file
uint8_t sync[2];
sync[0] = 0xb5;
sync[1] = 0x62;
```

but we are still missing observation packets ( b5 62 02 15 )

patcmorneau, 2022-05-19:
when the payload is bigger than 255 bytes, there's a byte ordering problem and the packets doesn't get written.
the payloads always exceed 255 bytes for observations packets

glabmoris, 2022-05-23:
Seems like a bug combo. lscpu shows that it's running in little-endian, so it's not an endianness bug, it appears that the bytes were just badly swapped at write time and that @patcmorneau 's fix solved that piece of the puzzle.

Furthermore, there was an issue in the binary read where the payload was not properly read. I noticed that we are using the read() syscall, which may not always return the proper amount of bytes. I've added a readSerial() method to handle this problem. Adding a check on incoming packets to find observation packets (b5 62 02 15) to print them out gives the expected result: Houston, we have obervation packets.

I'm going to be on the road, so could you please test that everything works with rtkconv and commit the codebase on the test hydroblock once confirmed?

Good job everyone!

glabmoris, 2022-05-24:
Great!

Can we generate a RINEX through rtkconv?

Ddoiron-cidco, 2022-05-24:
the obs file was send to NRCAN for PPP

i'am waiting for the result

Ddoiron-cidco, 2022-05-24:
i just recive the repport
[2022.pdf](https://github.com/CIDCO-dev/Poseidon/files/8765797/2022.pdf)

Ddoiron-cidco, 2022-05-27:
fixed

Closed 2022-05-27.

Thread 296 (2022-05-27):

[Raspberry pi 4] Heat management

Ddoiron-cidco, 2022-05-27:
we should look to add a fan on the raspberry

With a dicipator the temperature rice between 55 and 65C and the maximal is 80C

We should add a fan like :
https://www.waveshare.com/wiki/Fan_HAT
https://www.amazon.ca/-/fr/Waveshare-Ventilateur-Raspberry-temp%C3%A9rature-automatique/dp/B087PVD2GP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

glabmoris, 2024-10-21:
Fixed

Closed 2024-10-21.

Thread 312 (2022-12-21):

[node_zed_f9p] memory hole

Ddoiron-cidco, 2022-12-21:
after few day the node take over 4Go of RAM.

glabmoris, 2022-12-21:
The malloc() at line 366 doesn't have a free() in this file :

https://github.com/CIDCO-dev/Poseidon/blob/master/src/workspace/src/gnss_zed_f9p/include/gnss_zed_f9p/gnss_zed_f9p.h

Ddoiron-cidco, 2023-01-24:
FIXED !!

Closed 2023-01-24.

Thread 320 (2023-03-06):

[sonar_imagenex852] serial configuration in argument

Ddoiron-cidco, 2023-03-06:
add the serial port as in argument set in the launch files

glabmoris, 2024-10-21:
Fixed

Closed 2024-10-21.

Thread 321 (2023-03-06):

[sonar_nmea_0183_tcp_client] serial port and speed as argument

Ddoiron-cidco, 2023-03-06:
add serialport and speed as argument to be set in the launch files

glabmoris, 2024-10-21:
Fixed

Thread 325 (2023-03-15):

[Cellular connectivity] Problem concerning USB(RNDIS) device

Ddoiron-cidco, 2023-03-15:
The only equipment connecting with a USB port that Bell and Telus have available is LinkKey made by Alcatel
https://ca.alcatelmobile.com/alcatel-linkkey/

The device act as a router with a pseudo ethernet adapter based on RNDIS driver.
The device work on 4G

We get some isue with the device self disconnecting form the host computer.
I note that several people have experienced the same problem on several different forums. They all used computers running linux.

The manufacturer indicates that the cellular key is functional under linux but is not recommended.

Some people have indicated that using a cellular gateway with wifi or wired network was the best solution since the equipment uses real network interfaces.

It is important to understand that equipment working with RNDIS drivers such as the cellular usb key is a virtual network device.

Ddoiron-cidco, 2023-05-24:
The problem came from a node which had a memory leak.

The Node consumed all the available ram space, the kernel lacked RAM which caused different problems such as the loss of the USB ports and the non-responsiveness of the computer.

The problem was diagnosed using a bash script, which would create a file every hour, in the cron task. The bash script was making a file listing all the applications loaded in memory with the size of memory used.

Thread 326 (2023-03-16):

[Logger] Temporary data retention problem

Ddoiron-cidco, 2023-03-16:
the data in the directory /tmp is wiped at boot, so we lost last logged data after a power outage.

Proposed fix:
use a diferent directory like www/webroot/tmp
and when the logger start it will detect the presence of old file and compress the old files and move in the correct directory

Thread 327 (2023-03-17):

IMU calibration.dat

patcmorneau, 2023-03-17:
All the path in the launch files have been changed already.
for example in : `launch/Hydrobox/hydrobox_nmeadevice_ZED-F9P_bno055.launch`
we have :
```
<node ns="imu" name="imu_node" pkg="imu_bno055" type="bno055_i2c_node" respawn="true" respawn_delay="2" output="screen">
        <param name="device" type="string" value="/dev/i2c-1"/>
        <param name="address" type="int" value="40"/> <!-- 0x28 == 40 is the default for BNO055 -->
        <param name="frame_id" type="string" value="imu"/>
	<param name="calibrationFile" type="string" value="/opt/Poseidon/calibration.dat" />
```

but i still get the error message :
`[ERROR] [1679075054.482277046]: No calibration file found at /home/ubuntu/Poseidon/calibration.dat`

The error message is produced by: `bno055_i2c_activity.cpp` at line 120

in file `bno055_i2c_node.cpp`
we are passing the path `/home/ubuntu/Poseidon/calibration.dat` to the constructor

glabmoris, 2023-03-30:
Fixed in #319

Closed 2023-03-30.

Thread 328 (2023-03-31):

[enhancement]hostname

Ddoiron-cidco, 2023-03-31:
replace the hostname

Ddoiron-cidco, 2024-02-15:
Script ready and working in install/stage

Closed 2024-02-15.

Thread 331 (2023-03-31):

[web-interface] confinguration page

Ddoiron-cidco, 2023-03-31:
replace the dynamic page generation by static and with JS hide not used block

add block by type of content

sonar, csb connection .....

convert config.txt to json and validate json transmission on the web page
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

should be
[
  "apiKey": "C6388A4F547EBB1BCF4EF140C9F0363EC3952A28607BD182377D4FED9FE9FF076CAEA9E21E5767ABC95EF907903E84389498F0BCEB662E073EFE3B1C89C4D473"
  ,
  "apiTarget": "/CSBWeb/JobServlet"
 ,.....

glabmoris, 2024-10-21:
We have not reached a point where we have a fixed set of values to justify moving to static.

Closed 2024-10-21.

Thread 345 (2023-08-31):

Service executed by root

Ddoiron-cidco, 2023-08-31:
Services are executed by root should be executed by a user

Recommendation :

Clone github on current user
Create user Poseidon and copy workspace and www under poseidon home
Chown file and directory to the user Poseidon.
Copy the configuration file and calibration in the Home of poseidon if the are not present
Modify the service file for lighttpd to be launch by the user

patcmorneau, 2024-09-12:
in order the user to be able to communicate with i2c devices
```
sudo nano /etc/udev/rules.d/99-i2c.rules
KERNEL=="i2c-1", SUBSYSTEM=="i2c-dev", MODE="0660", OWNER="Poseidon"
sudo udevadm control --reload-rules
sudo udevadm trigger
```

glabmoris, 2024-10-21:
We need to have root access for GPIO access with the current ROS version.

Closed 2024-10-21.

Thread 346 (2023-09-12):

[Logger] stop to record and send data after 1 month

Ddoiron-cidco, 2023-09-12:
Active: active (running) since Tue 2023-07-18 20:38:21 UTC; 1 months 25 days ago
Main PID: 7614 (launchROSServic)
Tasks: 80 (limit: 9022)
CGroup: /system.slice/ros.service
├─7614 /bin/bash /opt/Poseidon/launchROSService.sh
├─7655 /usr/bin/python3 /opt/ros/noetic/bin/roslaunch /opt/Poseidon/src/workspace/launch/Hydrobox/hydrobox_rpi_nmeadevice_ZED-F9P_bno055.launch time_now:=2023.07.18_203822
├─7663 /usr/bin/python3 /opt/ros/noetic/bin/rosmaster --core -p 11311 -w 3 __log:=/root/.ros/log/09d45872-25ab-11ee-8339-edffc92effa0/master.log
├─7673 /opt/ros/noetic/lib/rosout/rosout __name:=rosout __log:=/root/.ros/log/09d45872-25ab-11ee-8339-edffc92effa0/rosout-1.log
├─7680 /opt/Poseidon/src/workspace/devel/lib/hydroball_config_websocket/hydroball_config_websocket_node /opt/Poseidon/config.txt __name:=hydroball_config_websocket __log:=/root/.ros/log/09d45872-25>
├─7681 /opt/Poseidon/src/workspace/devel/lib/imu_bno055/bno055_i2c_node __name:=imu_node __log:=/root/.ros/log/09d45872-25ab-11ee-8339-edffc92effa0/imu-imu_node-3.log
├─7683 /opt/Poseidon/src/workspace/devel/lib/gpsd_client/gpsd_client localhost 2947 __name:=GPS __log:=/root/.ros/log/09d45872-25ab-11ee-8339-edffc92effa0/GPS-4.log
├─7692 /opt/Poseidon/src/workspace/devel/lib/gnss_zed_f9p/gnss_zed_f9p_node /opt/Poseidon/www/webroot/record/ /dev/ttyACM0 __name:=gnss_zed_f9p __log:=/root/.ros/log/09d45872-25ab-11ee-8339-edffc92>
├─7696 /opt/Poseidon/src/workspace/devel/lib/sonar_nmea_0183_tcp_client/nmea_device_node __name:=Sonar __log:=/root/.ros/log/09d45872-25ab-11ee-8339-edffc92effa0/Sonar-6.log
├─7703 /opt/Poseidon/src/workspace/devel/lib/raspberrypi_vitals/raspberrypi_vitals_node __name:=Vitals __log:=/root/.ros/log/09d45872-25ab-11ee-8339-edffc92effa0/Vitals-7.log
├─7707 /opt/Poseidon/src/workspace/devel/lib/state_controller/state_controller_node __name:=state_controller __log:=/root/.ros/log/09d45872-25ab-11ee-8339-edffc92effa0/state_controller-8.log
├─7710 /opt/Poseidon/src/workspace/devel/lib/logger/logger_text_node /opt/Poseidon/www/webroot/record/ __name:=logger __log:=/root/.ros/log/09d45872-25ab-11ee-8339-edffc92effa0/logger-9.log
├─7718 /opt/Poseidon/src/workspace/devel/lib/hydroball_data_websocket/hydroball_data_websocket_node /opt/Poseidon/www/webroot/record/ __name:=hydroball_data_websocket __log:=/root/.ros/log/09d45872>
└─7723 /opt/Poseidon/src/workspace/devel/lib/hydroball_files_websocket/hydroball_files_websocket_node /opt/Poseidon/www/webroot/record/ __name:=hydroball_files_websocket __log:=/root/.ros/log/09d45>

Aug 18 03:36:51 ubuntu launchROSService.sh[121316]: adding: 2023.08.18_023648.ubx (deflated 43%)
Aug 18 03:36:51 ubuntu launchROSService.sh[121316]: test of /opt/Poseidon/www/webroot/record//2023.08.18_023648.zip OK
Aug 18 04:49:54 ubuntu launchROSService.sh[7710]: [ERROR] [1692334194.303278188]: Post request error: Connection timed out
Aug 18 05:49:54 ubuntu launchROSService.sh[121461]: adding: 2023.08.18_044954_gnss.txt (deflated 80%)
Aug 18 05:49:55 ubuntu launchROSService.sh[121461]: adding: 2023.08.18_044954_imu.txt (deflated 92%)
Aug 18 05:49:55 ubuntu launchROSService.sh[121461]: adding: 2023.08.18_044954_sonar.txt (deflated 76%)
Aug 18 05:49:55 ubuntu launchROSService.sh[121461]: adding: 2023.08.18_044954_lidar.txt (stored 0%)
Aug 18 05:49:57 ubuntu launchROSService.sh[121461]: adding: 2023.08.18_044954.ubx (deflated 42%)
Aug 18 05:49:57 ubuntu launchROSService.sh[121461]: test of /opt/Poseidon/www/webroot/record//2023.08.18_044954.zip OK
Sep 12 13:48:26 ubuntu launchROSService.sh[7680]: [2023-09-12 13:48:26] [error] handle_read_frame error: websocketpp.transport:7 (End of File)

glabmoris, 2024-10-21:
Fixed

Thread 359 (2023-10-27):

[Diagnostics] Ajouter test sur les horloges

glabmoris, 2023-10-27:
Ajouter un test de diagnostic pour la condition suivante:
On veut vérifier que le temps GNSS est le même que le temps système (+- 1ms)

Ddoiron-cidco, 2023-10-31:
Jai fait un petit script de test al nuit passer et je pense que ca pourais etre utile.

c'est un script python
on as a installer gpsd-py3 avec pip

```
import gps
import time
from datetime import datetime

# Connectez-vous à GPSD
session = gps.gps("localhost", "2947")
session.stream(gps.WATCH_ENABLE | gps.WATCH_NEWSTYLE)

try:
    while True:
        report = session.next()
        if report['class'] == 'TPV':
            if hasattr(report, 'time'):
                gps_time = report.time
                system_time = time.time()
                time_difference = gps_time - system_time
                gps_time_str = datetime.utcfromtimestamp(gps_time).strftime('%Y-%m-%d %H:%M:%S')
                system_time_str = datetime.utcfromtimestamp(system_time).strftime('%Y-%m-%d %H:%M:%S')
                print(f"GPS Time: {gps_time_str}")
                print(f"System Time: {system_time_str}")
                print(f"Time Difference (seconds): {time_difference}")
                break

except KeyboardInterrupt:
    session.close()

```

patcmorneau, 2023-11-02:
`chronyc sources`  nmea donne +/- 101 ms...

Et le test dans le PR#305 donne en moyenne 500 ms

Ddoiron-cidco, 2024-05-07:
@glabmoris

https://github.com/Ddoiron-cidco/Poseidon/blob/0b595d9a41a7ae311224cf4acdaf5372db666673/install/stages/5-finalize.sh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

offset 0.5 seconde = 500ms

the delay could be adjusted too.

glabmoris, 2024-10-21:
Set this test to < 30ms

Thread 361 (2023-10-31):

[Diagnostics] Valider si le numéro de série a été apliqué

Ddoiron-cidco, 2023-10-31:
On pourais ajouter un test pour valider que le numéro de série est appliquer sur le rpi.

Le numéro de série est enregistrer dans le hostname.
Par défaut le hostname sur un raspberry est ubuntu mais sur un pc normal ca peut etre normal.

Il faut valider que le hostname est sous cette structure

AAAAAA-000000-111
La partie AAAAAA peut etre composer de 2 a 8 caractere
la partie 000000 est composé de la date
la partie 111 est composé de l'identification de l'unité journalierre

Ex.
CIDCO-230806-003
M2Ocean-230406-012

Ddoiron-cidco, 2024-02-15:
le test est bien fonctionnel
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

Closed 2024-02-15.

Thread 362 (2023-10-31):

[Diagnostics] IMU Offset

Ddoiron-cidco, 2023-10-31:
IMU Offset not aplied durign the test

Ddoiron-cidco, 2023-11-01:
error in the diagnostic node fixed

Closed 2023-11-01.

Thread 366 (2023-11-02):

[Sonar_Imagenex_852] Data transmission fron the node

Ddoiron-cidco, 2023-11-02:
Every less than a second the node transmit data to the sonar on the serial port causing the sonar to respond with the depth.

If the pps is present the Sonar is not syncronised with the PPS and the sonar ping are not tuned on a perfect 1hz

If the pps is disconnected the sonar continue to transmit the depth and are still not tuned on a perfect 1hz

I'made a small python script to test the sonar and the ability to transmit on the pps and it work well.

```
import serial

port = '/dev/sonar'
baudrate = 115200

ser = serial.Serial(port, baudrate=baudrate)
parity = serial.PARITY_NONE
bytesize = 8
stopbits = 1

ser = serial.Serial(port, baudrate=baudrate, parity=parity, bytesize=bytesize, stopbits=stopbits)

try:
    init_data = bytes([0xFE, 0x44, 0x11, 0x32, 0x00, 0x00, 0x43, 0x00, 0x06, 0x00, 0x20, 0x00, 0x00, 0x00, 150, 32, 0x00, 0x00, 0x07, 0, 0, 0, 1, 0, 0, 0, 0xFD])
    ser.write(init_data)

    while True:
        response = ser.read(13)
        print("sonar responce:", response)

finally:
    ser.close()
```

Closed 2024-02-20.

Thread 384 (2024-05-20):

[Vitals / logger]

Ddoiron-cidco, 2024-05-20:
Vitals node report hdd full when it is not the case
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

the dashboard indicate the error
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

but the system is still logging new data

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

glabmoris, 2024-10-21:
Cannot reproduce

Closed 2024-10-21.

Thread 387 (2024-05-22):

[Logger / websocket] No data stream to the web interface and no logging during file transfert

Ddoiron-cidco, 2024-05-22:
during the files transfert to the CSB plateform and the file compression the websocket of the dashboard stop to send new data to the web interface and no data are logged on the disk

patcmorneau, 2024-09-12:
I suggest we try running the logger nodes in their own thread or we can move the the compress and transfer logic in an other node that will run in its own thread

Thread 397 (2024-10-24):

dashboardscript.js

Ddoiron-cidco, 2024-10-24:
If no gnss data is send by the websocket the web interface is stuck in loading mode
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

add a check to the lenght or the pressence of the value of "position"
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

Ddoiron-cidco, 2024-11-22:
fix in #412

Closed 2024-11-22.

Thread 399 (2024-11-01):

[WEB - System Status] Hide sensor information when not prensent

Ddoiron-cidco, 2024-11-01:
Whe the sensor are not present in the device the value is set to -666

add a condition if value = -666 hide the information about the sensor

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

Ddoiron-cidco, 2024-11-22:
the value is replaced by -555  and the javascript hide the information of the missing sensors

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

Ddoiron-cidco, 2024-11-22:
fix in #412

Closed 2024-11-22.

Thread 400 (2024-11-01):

[I2C Controller] fail if I2C4 not activated

Ddoiron-cidco, 2024-11-01:
if i2c4 is not activated the node failed to run

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

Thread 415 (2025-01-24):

Hydroball led error

Ddoiron-cidco, 2025-01-24:
Hydroball led turn red if the battery voltage is > 13v and sould be >13.8v

Ddoiron-cidco, 2025-03-19:
fix in #423

Closed 2025-03-19.

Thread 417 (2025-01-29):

[System Status] LED on eror turn yellow/orange no detail on wen interface

Ddoiron-cidco, 2025-01-29:
When the led indicate error or no gnss fix we have no information on the web interface

Ddoiron-cidco, 2025-03-19:
fix in #418 and #423

Closed 2025-03-19.

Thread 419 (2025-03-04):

Status LED go from ready to error.

Ddoiron-cidco, 2025-03-04:
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

Ddoiron-cidco, 2025-03-04:
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

issue fix and more informations on the dashboard web page.

Closed 2025-03-04.

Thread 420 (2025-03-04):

if the GNSS have already 3D fix the led didnt lit green

Ddoiron-cidco, 2025-03-04:

Ddoiron-cidco, 2025-03-19:
fix in #418

Closed 2025-03-19.

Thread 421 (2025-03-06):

Automatic rebooting of device

glabmoris, 2025-03-06:
External events may cause the raspberry pi to hang. Rebooting on a daily basis may mitigate this issue.

Other suggestions:
-  Make reboot delay configurable through UI

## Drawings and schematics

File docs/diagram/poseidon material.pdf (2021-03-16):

Hydro B.

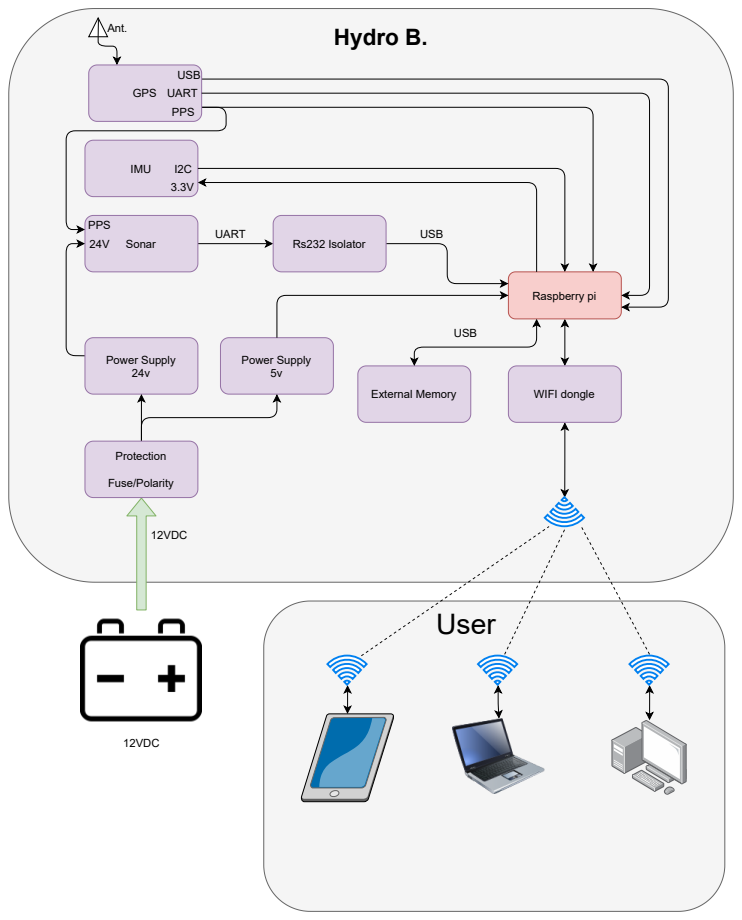
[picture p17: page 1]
Raspberry pi; External Memory; Power Supply 5v; Sonar; IMU; GPS; 12VDC; USB; Rs232 Isolator; UART; PPS; Ant.; Power Supply 24v; Protection; Fuse/Polarity; User; WIFI dongle

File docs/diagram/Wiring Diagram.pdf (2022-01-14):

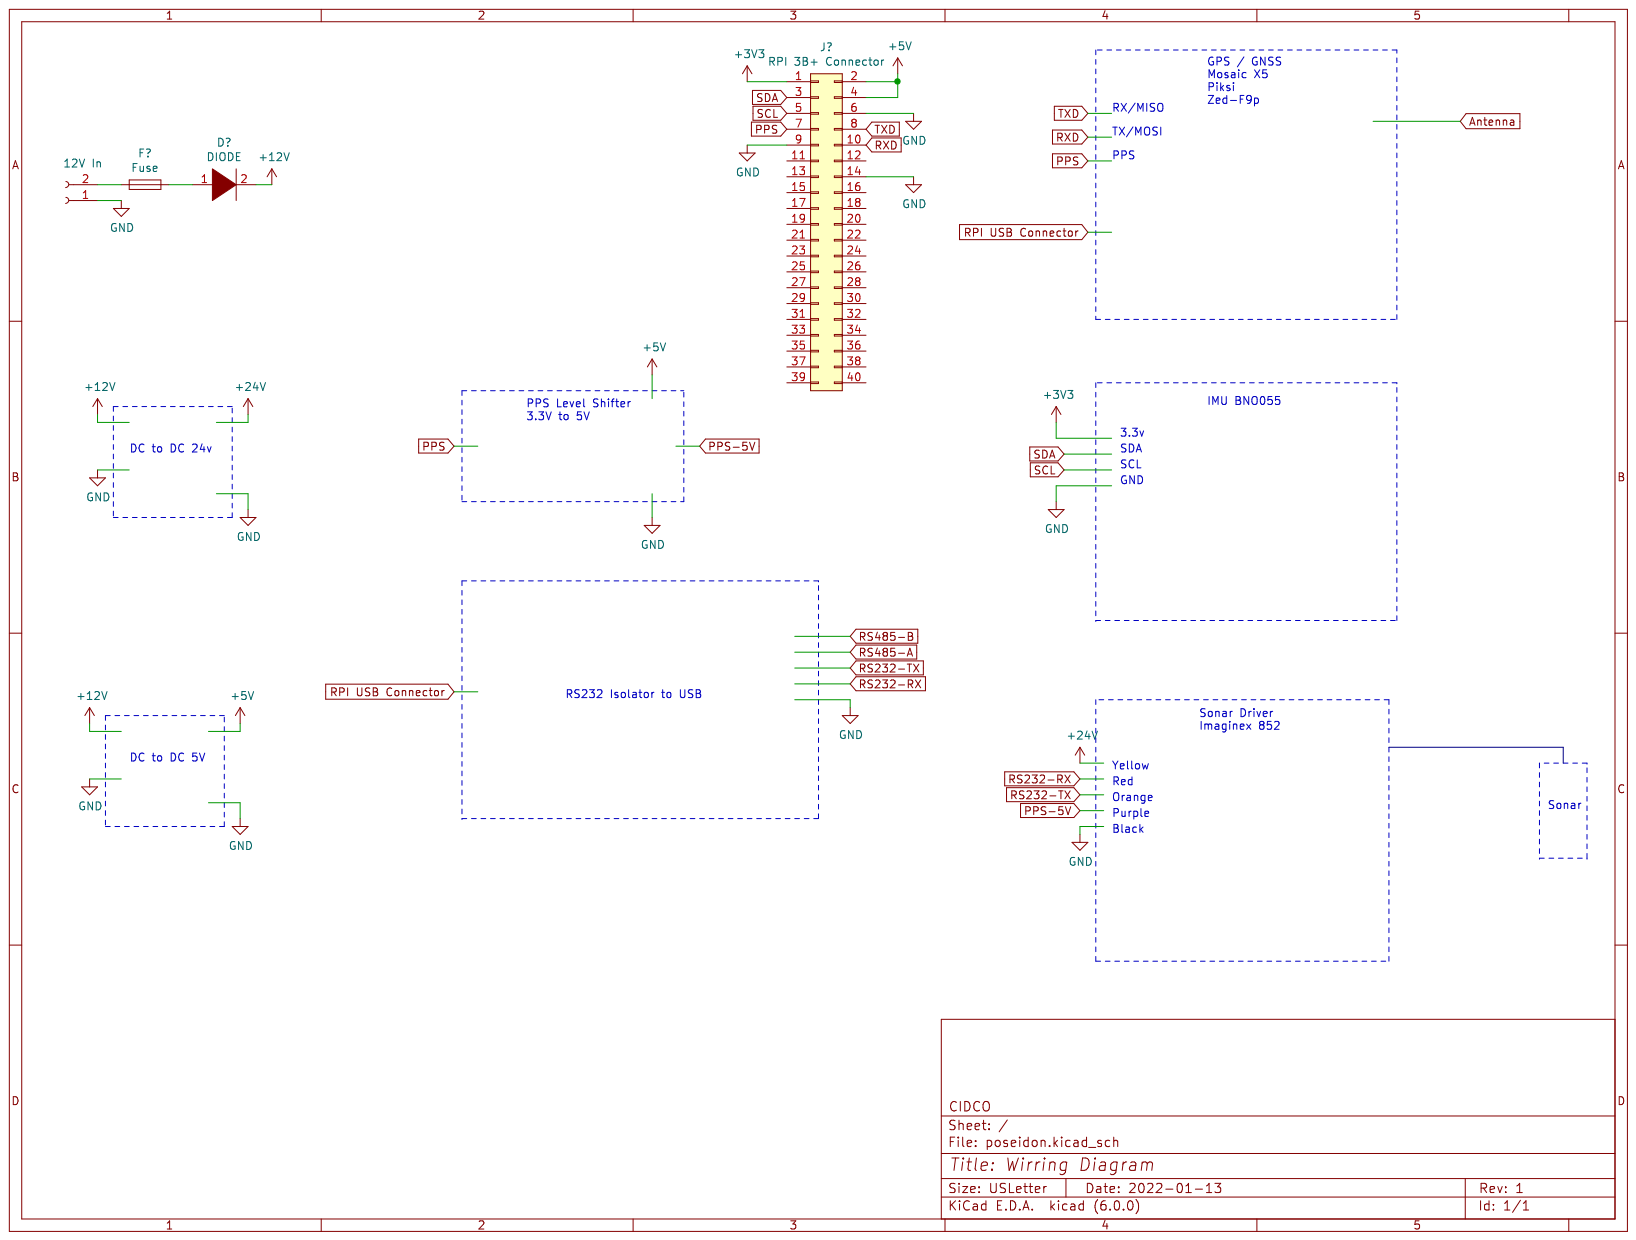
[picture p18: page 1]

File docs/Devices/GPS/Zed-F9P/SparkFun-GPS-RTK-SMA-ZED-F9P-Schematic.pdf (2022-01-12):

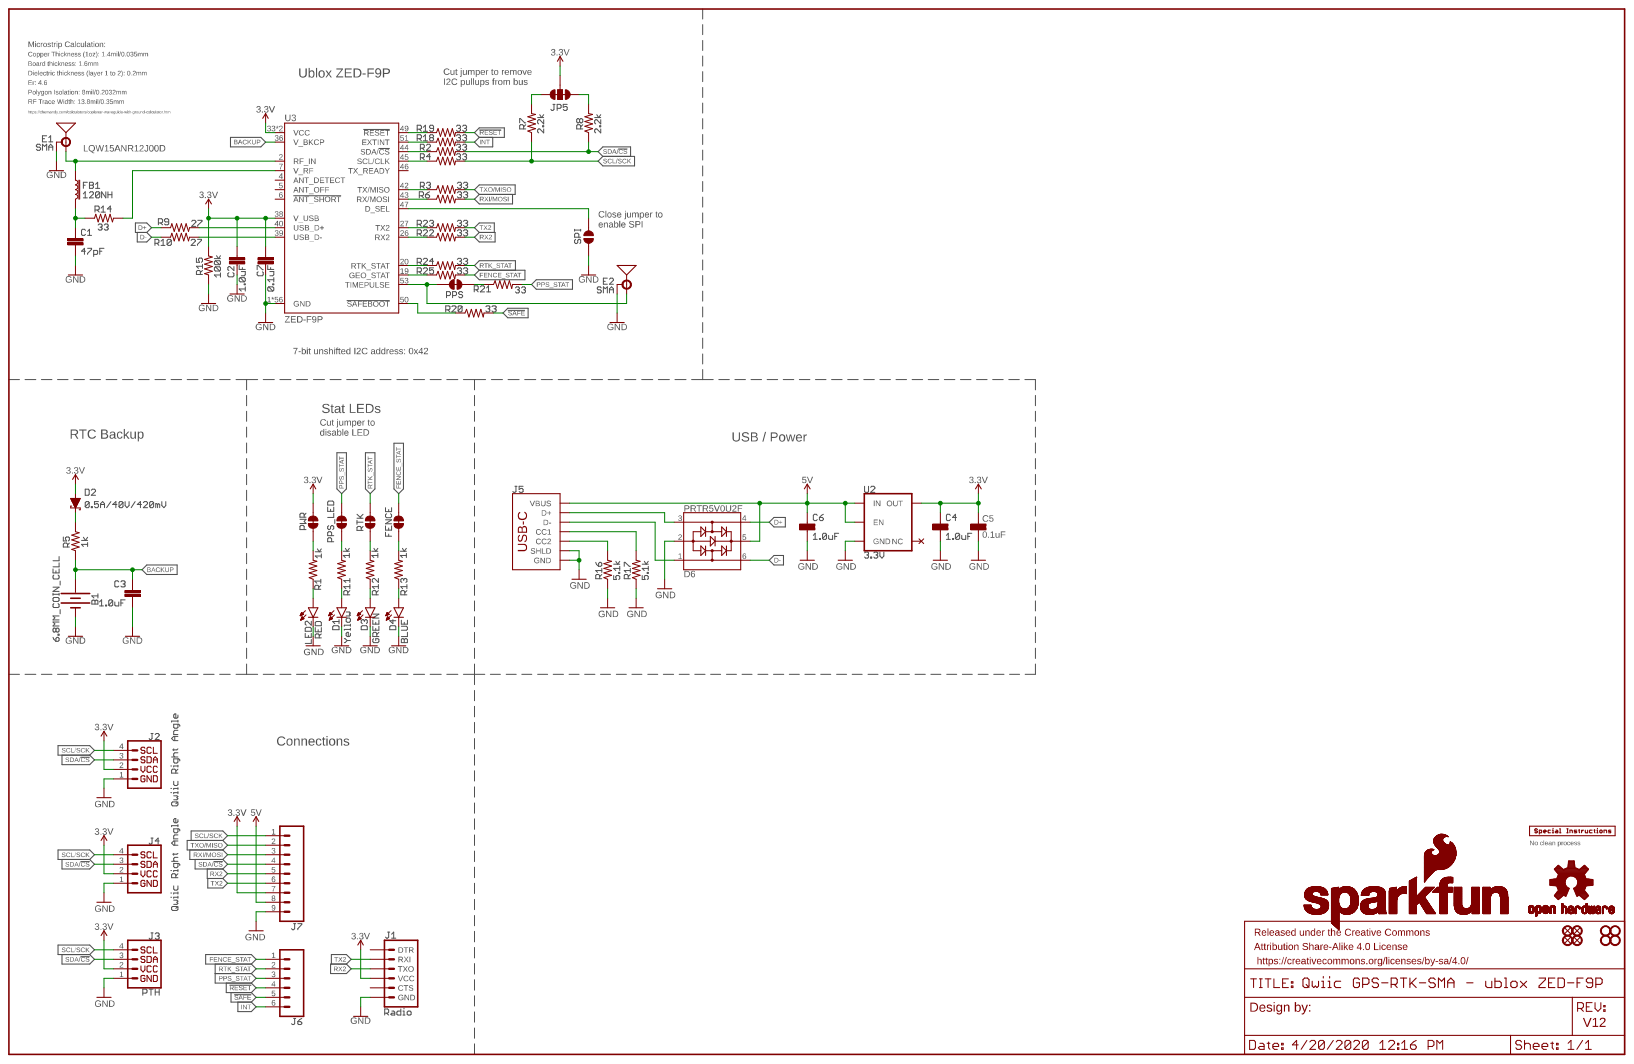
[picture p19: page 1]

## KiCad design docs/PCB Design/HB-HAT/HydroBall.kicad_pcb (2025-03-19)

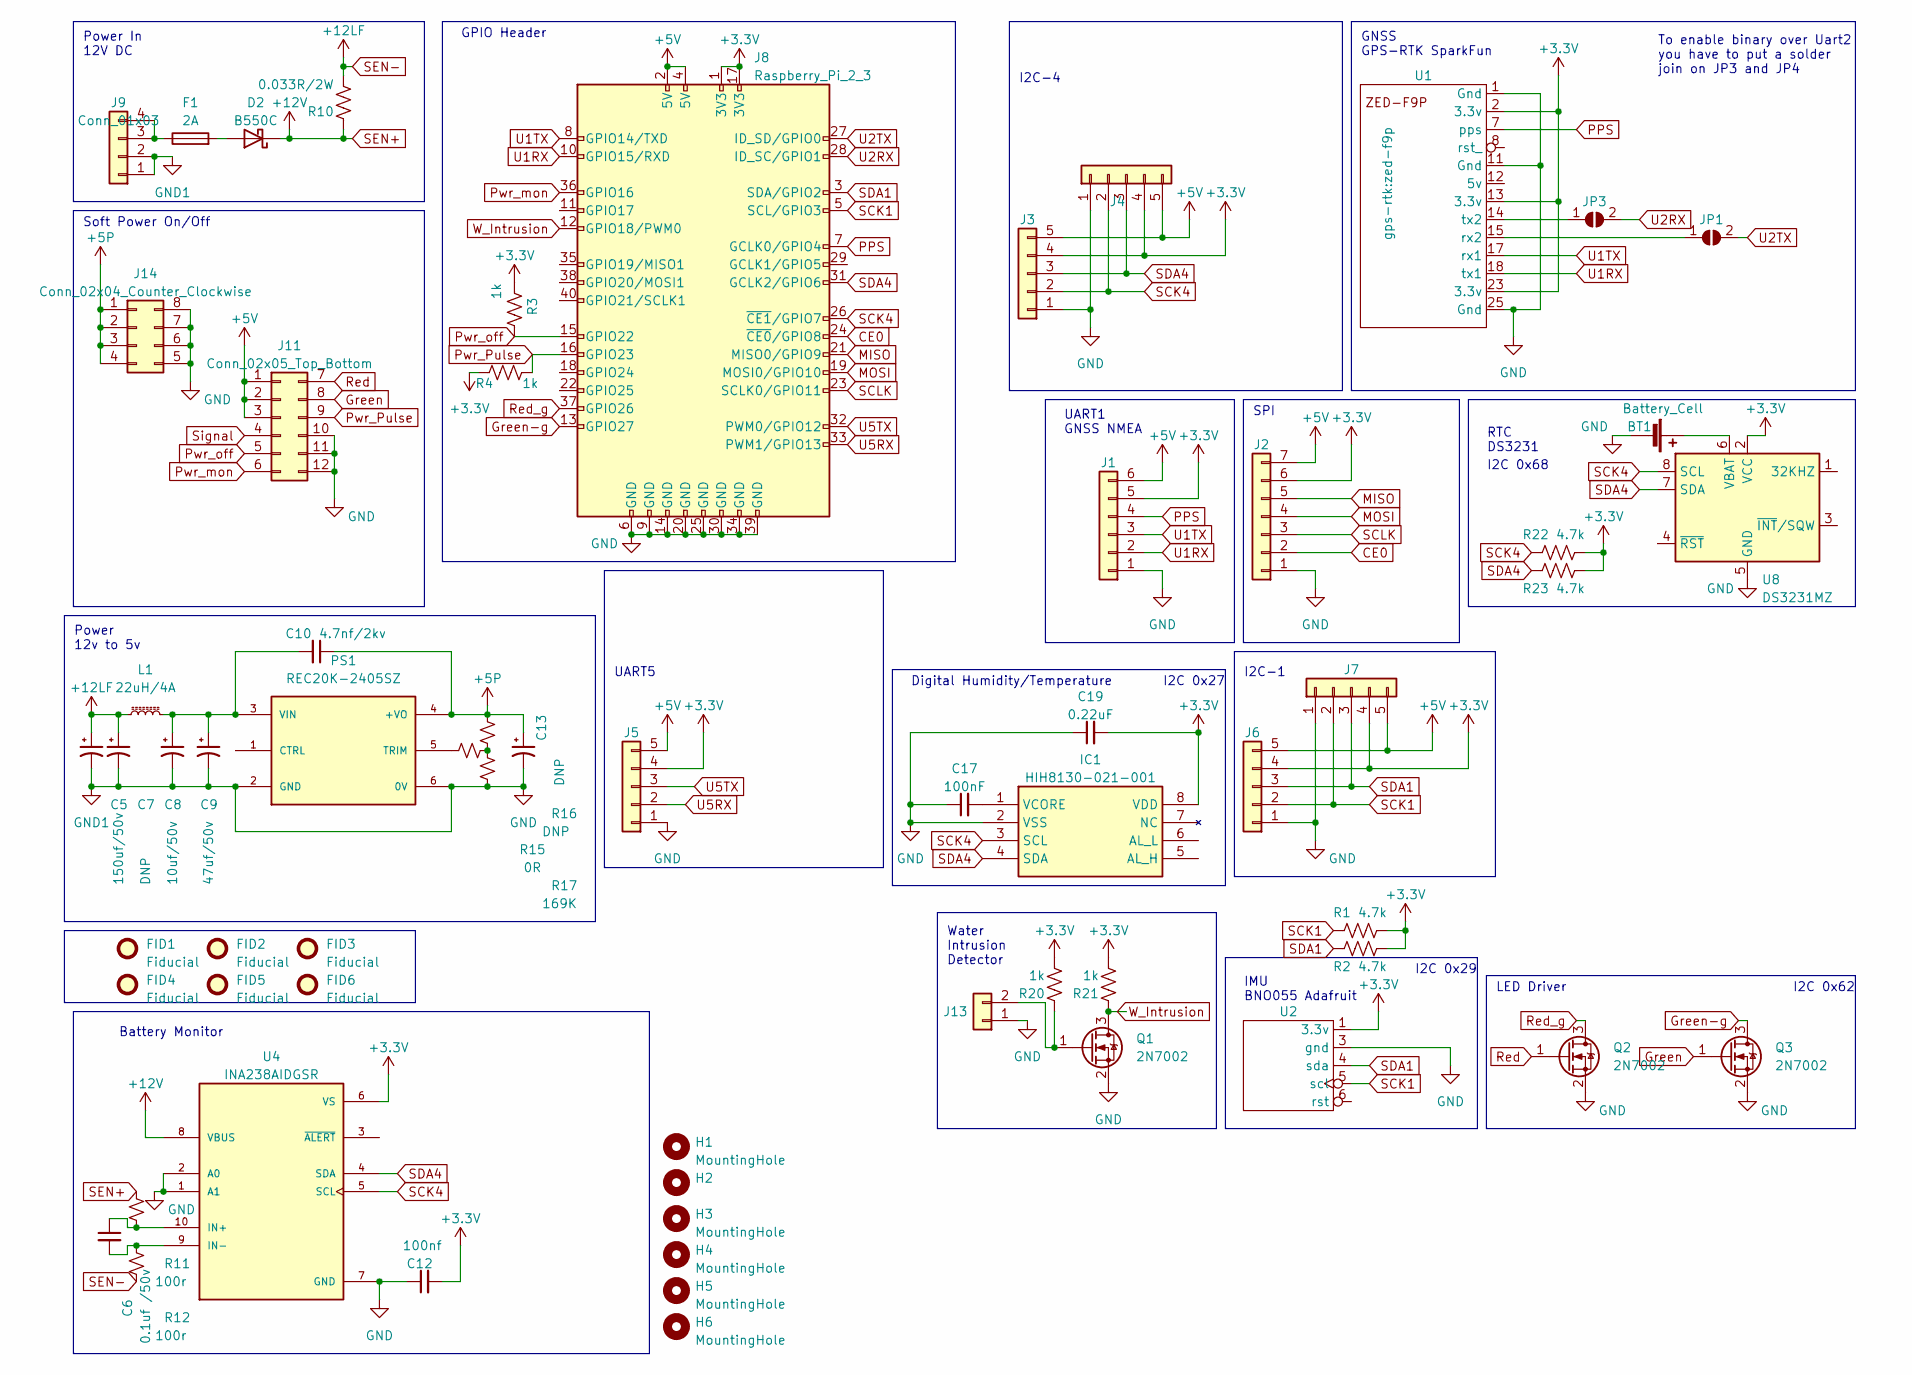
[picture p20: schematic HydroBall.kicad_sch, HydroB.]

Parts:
BT1: Battery_Cell; BatteryHolder_Keystone_1058_1x2032
C5: 150uf/50v; CP_Radial_D10.0mm_P5.00mm
C6: 0.1uf /50v; C_1206_3216Metric
C7: DNP; C_1206_3216Metric
C8: 10uf/50v; C_1206_3216Metric
C9: 47uf/50v; CP_Radial_D10.0mm_P5.00mm
C10: 4.7nf/2kv; C_1206_3216Metric
C12: 100nf; C_1206_3216Metric
C13: DNP; CP_Elec_6.3x9.9
C17: 100nF; C_1206_3216Metric
C19: 0.22uF; C_1206_3216Metric
D2: B550C; D_SMC
F1: 2A; Fuse_1206_3216Metric
FID1, FID2, FID3, FID4, FID5, FID6: Fiducial; Fiducial_0.75mm_Mask2.25mm
H1, H2, H3, H4, H5, H6: MountingHole; MountingHole_2.7mm_M2.5_ISO7380_Pad
IC1: HIH8130-021-001; SOIC127P600X206-8N; Mouser Part Number 785-HIH8130-021-001
J1: Conn_01x05; JST_XH_B6B-XH-AM_1x06_P2.50mm_Vertical
J2: Conn_01x07; JST_XH_B7B-XH-AM_1x07_P2.50mm_Vertical
J3, J4, J6, J7: Conn_01x05; JST_XH_B5B-XH-AM_1x05_P2.50mm_Vertical
J5: Conn_01x06; JST_XH_B5B-XH-AM_1x05_P2.50mm_Vertical
J8: Raspberry_Pi_2_3; PinSocket_2x20_P2.54mm_Vertical
J9: Conn_01x03; PhoenixContact_MSTBVA_2,5_4-G-5,08_1x04_P5.08mm_Vertical
J11: Conn_02x05_Top_Bottom; PinHeader_2x06_P2.54mm_Vertical
J13: Conn_01x06; JST_XH_B2B-XH-AM_1x02_P2.50mm_Vertical
J14: Conn_02x04_Counter_Clockwise; PinHeader_2x04_P2.54mm_Vertical
JP1, JP3: SolderJumper_2_Open; SolderJumper-2_P1.3mm_Open_RoundedPad1.0x1.5mm
L1: 22uH/4A; L_1210_3225Metric
PS1: REC20K-2405SZ; CONV_PDQE20-Q24-S5-D; PARTREV 1.0
Q1, Q2, Q3: 2N7002; SOT-23
R1, R2, R22, R23: 4.7k; R_1206_3216Metric
R3, R4, R20, R21: 1k; R_1206_3216Metric
R10: 0.033R/2W; R_2512_6332Metric
R11, R12: 100r; R_1206_3216Metric
R15: 0R; R_1206_3216Metric
R16: DNP; R_1206_3216Metric
R17: 169K; R_1206_3216Metric
U1: zed-f9p
U2: bno055
U4: INA238AIDGSR; SOP50P490X110-10N; PARTREV A
U8: DS3231MZ; SOIC-8_3.9x4.9mm_P1.27mm

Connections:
+3.3V: C12.2, C19.2, IC1.8 (VDD), J1.5, J2.6, J3.4, J4.4, J5.4, J6.4, J7.4, J8.1 (3V3), J8.17 (3V3), R1.2, R2.2, R3.2, R4.2, R20.2, R21.2, R22.2, R23.2, U1.2 (3.3v), U1.13 (3.3v), U1.23 (3.3v), U2.1 (3.3v), U4.6 (VS), U8.2 (VCC)
+5P: C10.1, C13.1, J14.1, J14.2, J14.3, J14.4, PS1.4 (+VO), R16.1
+5V: J1.6, J2.7, J3.5, J4.5, J5.5, J6.5, J7.5, J8.2 (5V), J8.4 (5V), J11.1, J11.2, J11.3
CE0: J2.2, J8.24 (~CE0/GPIO8)
GND: BT1.2 (-), C5.2, C7.2, C8.2, C9.2, C12.1, C13.2, C17.1, C19.1, IC1.2 (VSS), J1.1, J2.1, J3.1, J4.1, J5.1, J6.1, J7.1, J8.6 (GND), J8.9 (GND), J8.14 (GND), J8.20 (GND), J8.25 (GND), J8.30 (GND), J8.34 (GND), J8.39 (GND), J9.1, J9.2, J11.10, J11.11, J11.12, J13.1, J14.5, J14.6, J14.7, J14.8, PS1.2 (GND), PS1.6 (0V), Q1.2 (S), Q2.2 (S), Q3.2 (S), R17.2, U1.1 (Gnd), U1.11 (Gnd), U1.25 (Gnd), U2.3 (gnd), U4.1 (A1), U4.2 (A0), U4.7 (GND), U8.5 (GND)
Green: J11.8, Q3.1 (G)
Green-g: J8.13 (GPIO27), Q3.3 (D)
MISO: J2.5, J8.21 (MISO0/GPIO9)
MOSI: J2.4, J8.19 (MOSI0/GPIO10)
unnamed: BT1.1 (+), U8.6 (VBAT)
unnamed: D2.2 (A), F1.2
unnamed: C17.2, IC1.1 (VCORE)
unnamed: F1.1, J9.3, J9.4
unnamed: J13.2, Q1.1 (G), R20.1
unnamed: JP1.1 (A), U1.15 (rx2)
unnamed: JP3.1 (A), U1.14 (tx2)
unnamed: PS1.5 (TRIM), R15.1
unnamed: C8.1, C9.1, C10.2, L1.2, PS1.3 (VIN)
unnamed: R15.2, R16.2, R17.1
unnamed: C6.1, R11.2, U4.10 (IN+)
unnamed: C6.2, R12.1, U4.9 (IN-)
PPS: J1.4, J8.7 (GCLK0/GPIO4), U1.7 (pps)
Pwr_Pulse: J8.16 (GPIO23), J11.9, R4.1
Pwr_mon: J8.36 (GPIO16), J11.6
Pwr_off: J8.15 (GPIO22), J11.5, R3.1
Red: J11.7, Q2.1 (G)
Red_g: J8.37 (GPIO26), Q2.3 (D)
SCK1: J6.2, J7.2, J8.5 (SCL/GPIO3), R1.1, U2.5 (scl)
SCK4: IC1.3 (SCL), J3.2, J4.2, J8.26 (~CE1/GPIO7), R22.1, U4.5 (SCL), U8.8 (SCL)
SCLK: J2.3, J8.23 (SCLK0/GPIO11)
SDA1: J6.3, J7.3, J8.3 (SDA/GPIO2), R2.1, U2.4 (sda)
SDA4: IC1.4 (SDA), J3.3, J4.3, J8.31 (GCLK2/GPIO6), R23.1, U4.4 (SDA), U8.7 (SDA)
SEN+: D2.1 (K), R10.1, R11.1, U4.8 (VBUS)
SEN-: C5.1, C7.1, L1.1, R10.2, R12.2
Signal: J11.4
U1RX: J1.2, J8.10 (GPIO15/RXD), U1.18 (tx1)
U1TX: J1.3, J8.8 (GPIO14/TXD), U1.17 (rx1)
U2RX: J8.28 (ID_SC/GPIO1), JP3.2 (B)
U2TX: J8.27 (ID_SD/GPIO0), JP1.2 (B)
U5RX: J5.2, J8.33 (PWM1/GPIO13)
U5TX: J5.3, J8.32 (PWM0/GPIO12)
W_Intrusion: J8.12 (GPIO18/PWM0), Q1.3 (D), R21.1

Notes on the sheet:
SPI
Water Intrusion Detector
I2C 0x68
Soft Power On/Off
Battery Monitor
GPIO Header
I2C 0x29
I2C-1
LED Driver
Power In 12V DC
I2C 0x27
RTC DS3231
GNSS GPS-RTK SparkFun
I2C 0x62
To enable binary over Uart2 you have to put a solder join on JP3 and JP4
UART5
Power 12v to 5v
I2C-4
IMU BNO055 Adafruit
Digital Humidity/Temperature
UART1 GNSS NMEA

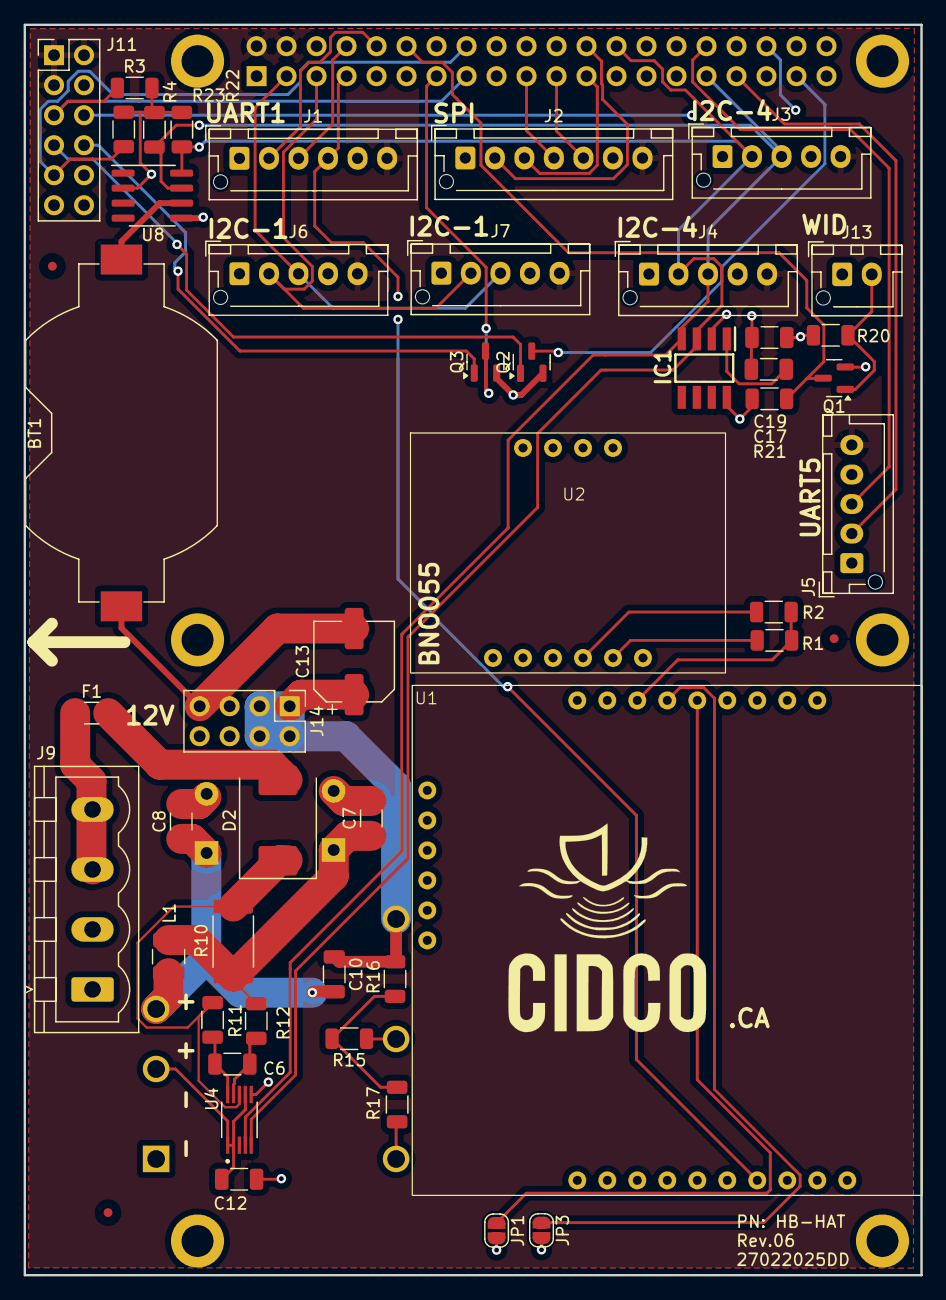
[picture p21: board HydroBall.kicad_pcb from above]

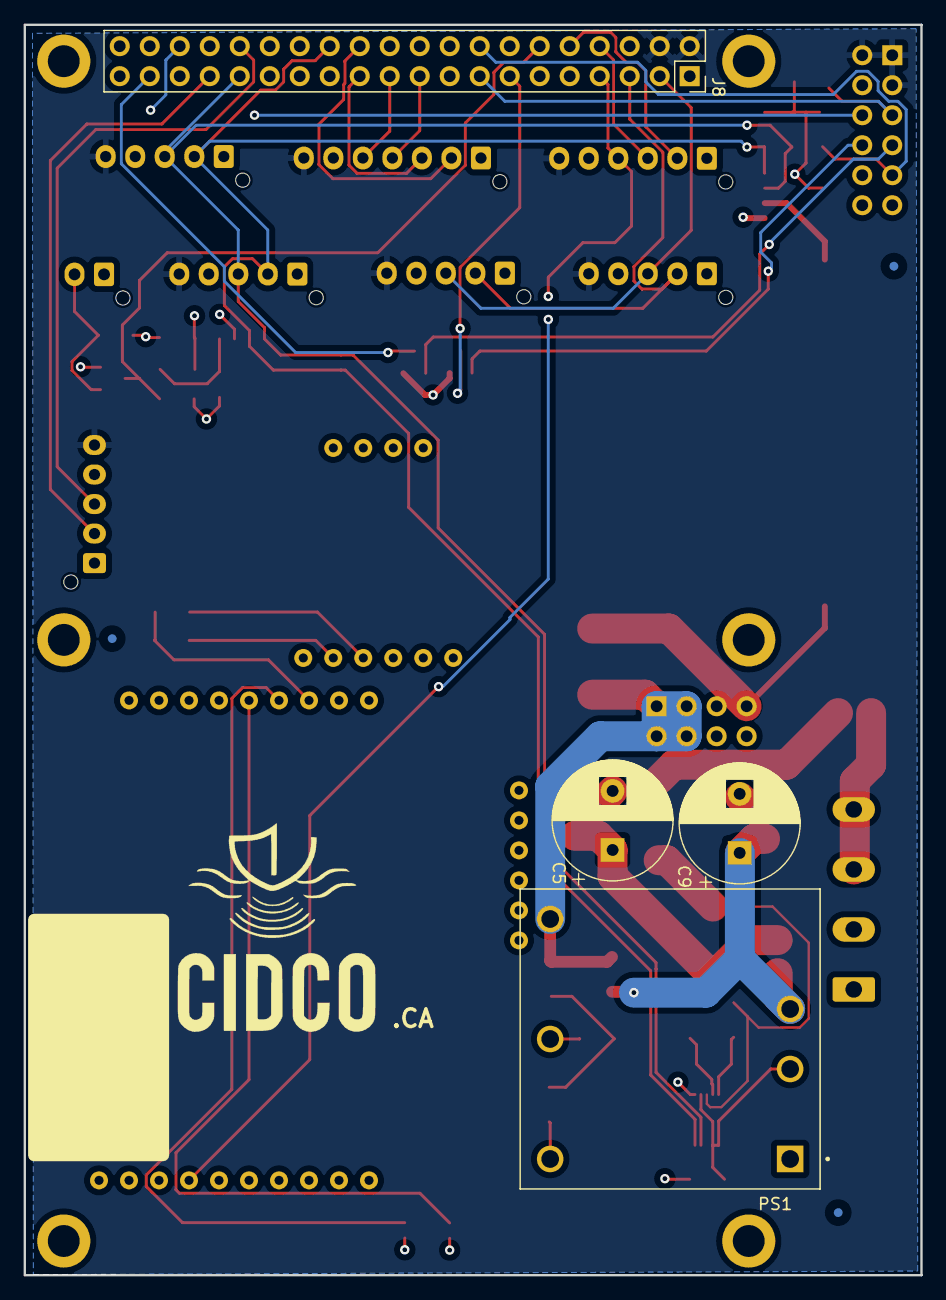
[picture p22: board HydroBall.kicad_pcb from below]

Board: 4 copper layers, 75.9 x 105.9 mm, 65 parts (8 on the bottom side), 41 nets.

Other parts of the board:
logo1, logo1#2: LOGO; logo cidco

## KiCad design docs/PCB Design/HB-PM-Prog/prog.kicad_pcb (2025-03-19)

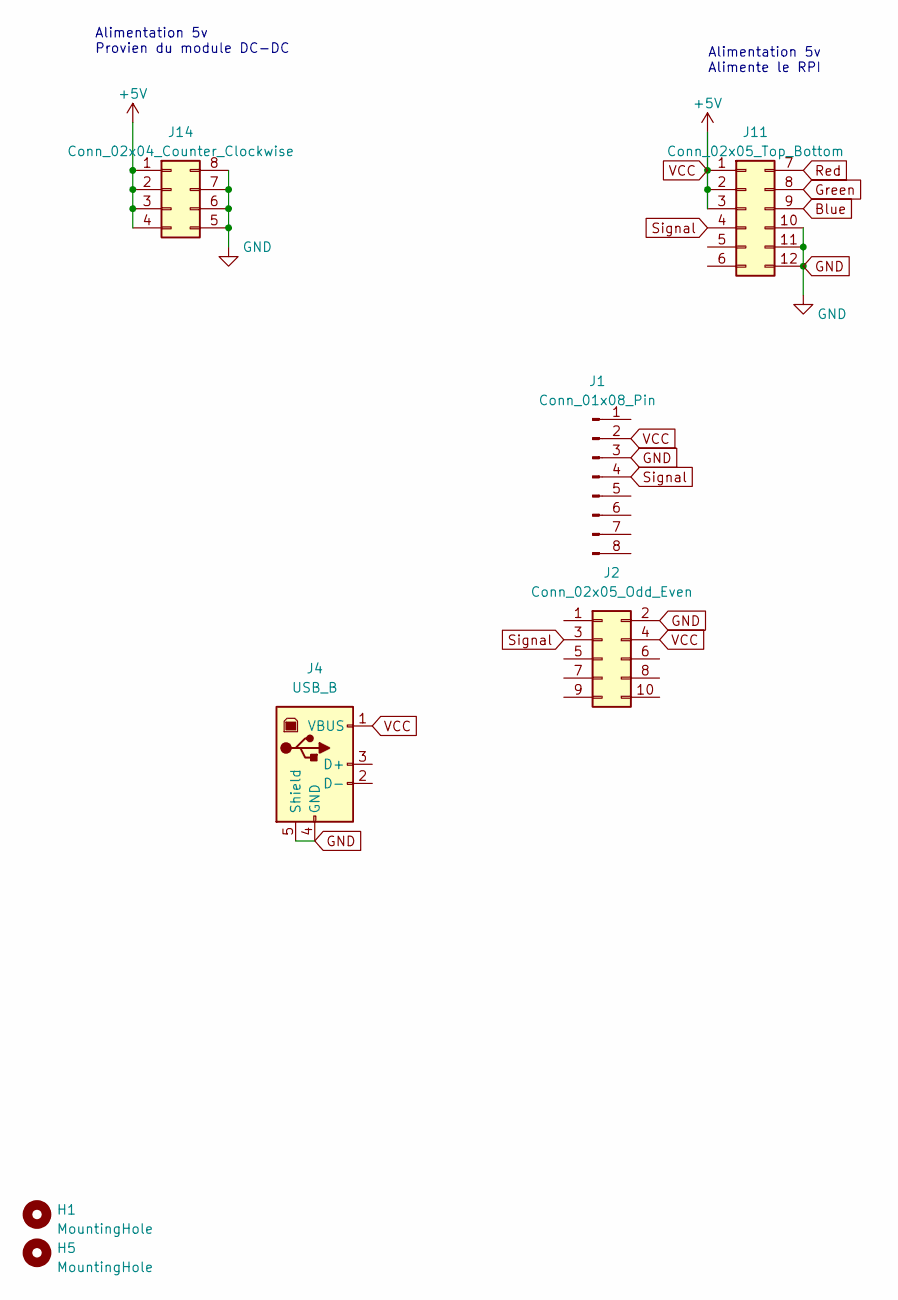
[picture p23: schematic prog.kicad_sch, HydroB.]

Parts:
H1, H5: MountingHole; MountingHole_2.7mm_M2.5_ISO7380_Pad
J1: Conn_01x08_Pin; PinHeader_1x08_P2.54mm_Horizontal
J2: Conn_02x05_Odd_Even; IDC-Header_2x05_P2.54mm_Vertical
J4: USB_B; USB_B_Lumberg_2411_02_Horizontal
J11: Conn_02x05_Top_Bottom; PinHeader_2x06_P2.54mm_Vertical
J14: Conn_02x04_Counter_Clockwise; PinHeader_2x04_P2.54mm_Vertical

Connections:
Blue: J11.9
GND: J1.3, J2.2, J4.4 (GND), J4.5 (Shield), J11.10, J11.11, J11.12, J14.5, J14.6, J14.7, J14.8
Green: J11.8
Red: J11.7
Signal: J1.4, J2.3, J11.4
VCC: J1.2, J2.4, J4.1 (VBUS), J11.1, J11.2, J11.3, J14.1, J14.2, J14.3, J14.4

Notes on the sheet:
Alimentation 5v Alimente le RPI
Alimentation 5v Provien du module DC-DC

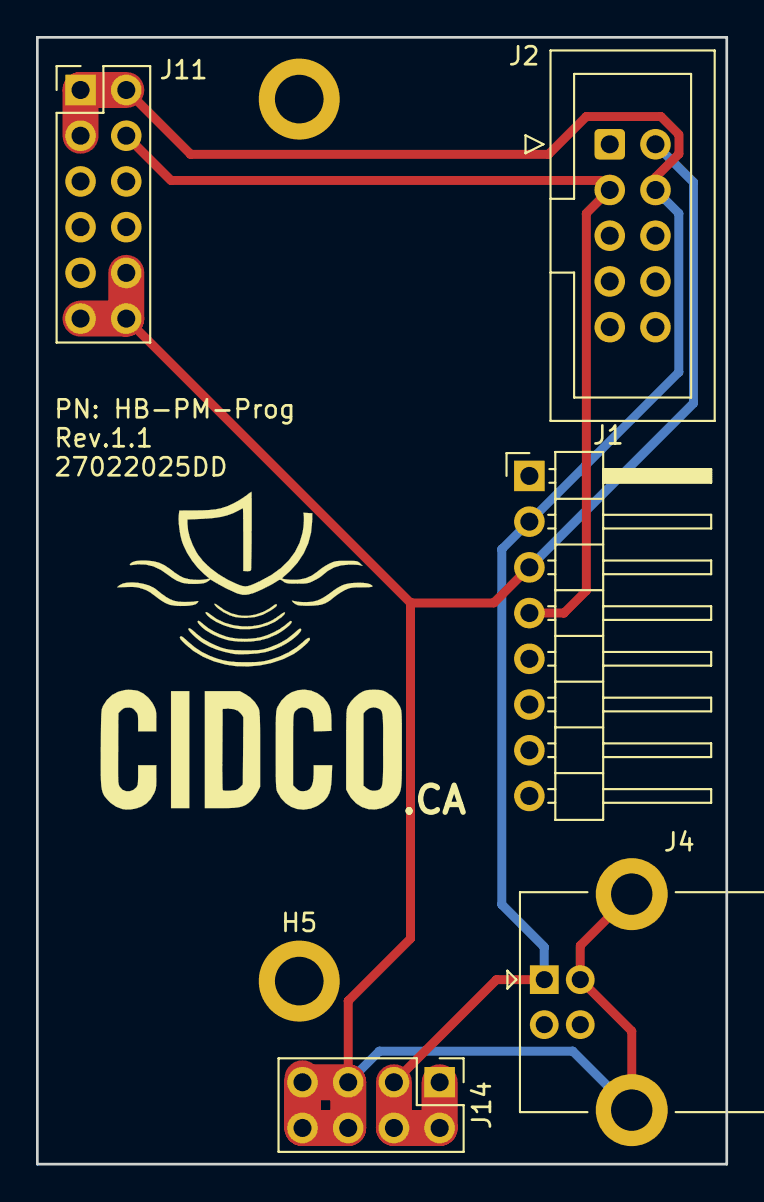
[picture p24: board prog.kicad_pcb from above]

Board: 2 copper layers, 38.3 x 62.6 mm, 8 parts (0 on the bottom side), 3 nets.

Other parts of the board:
logo1: LOGO; logo cidco

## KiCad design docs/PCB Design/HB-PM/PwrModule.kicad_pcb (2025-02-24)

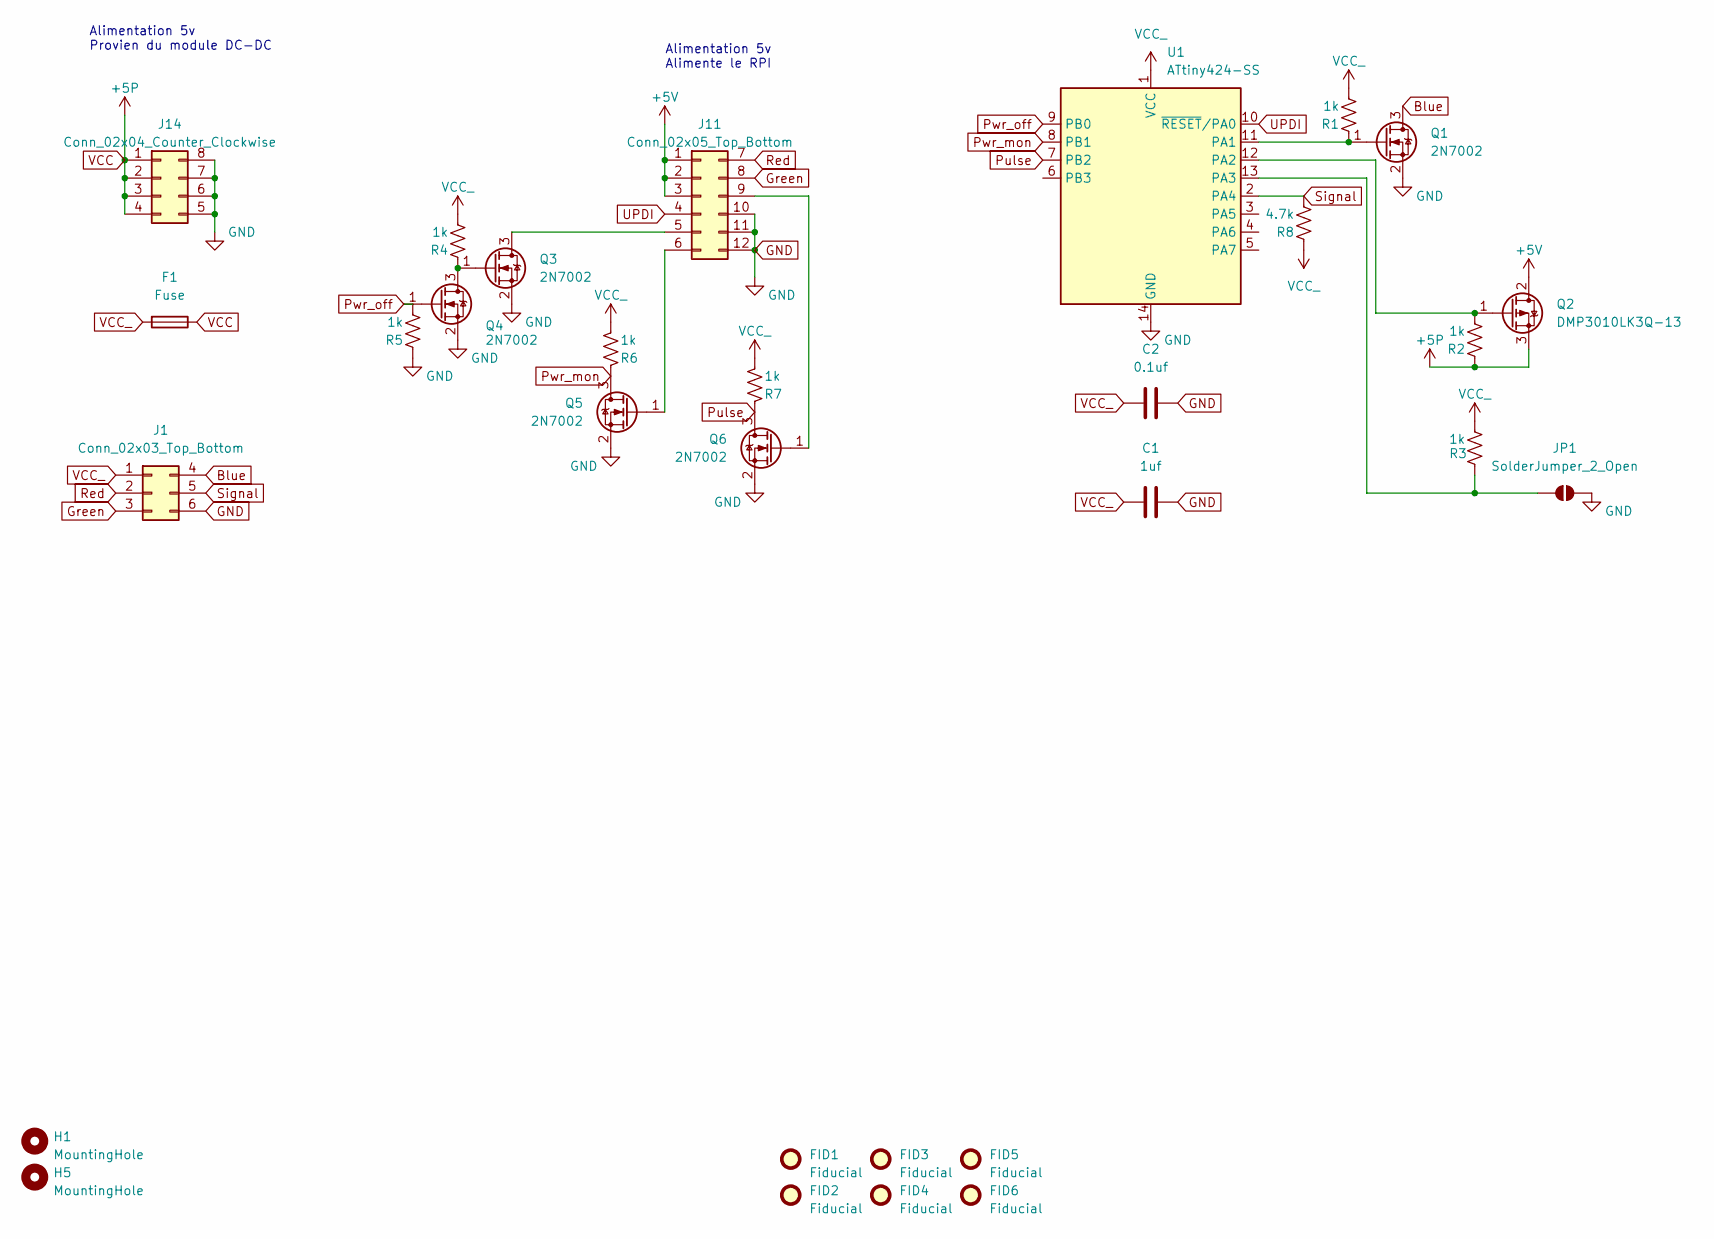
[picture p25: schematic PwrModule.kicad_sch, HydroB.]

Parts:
C1: 1uf; C_1206_3216Metric
C2: 0.1uf; C_1206_3216Metric
F1: Fuse; Fuse_1206_3216Metric
FID1, FID2, FID3, FID4, FID5, FID6: Fiducial; Fiducial_0.75mm_Mask2.25mm
H1, H5: MountingHole; MountingHole_2.7mm_M2.5_ISO7380_Pad
J1: Conn_02x03_Top_Bottom; IDC-Header_2x03_P2.54mm_Vertical
J11: Conn_02x05_Top_Bottom; PinHeader_2x06_P2.54mm_Vertical
J14: Conn_02x04_Counter_Clockwise; PinHeader_2x04_P2.54mm_Vertical
JP1: SolderJumper_2_Open; SolderJumper-2_P1.3mm_Open_TrianglePad1.0x1.5mm
Q1, Q3, Q4, Q5, Q6: 2N7002; SOT-23
Q2: DMP3010LK3Q-13; TO-252-2
R1, R2, R3, R4, R5, R6, R7: 1k; R_1206_3216Metric
R8: 4.7k; R_1206_3216Metric
U1: ATtiny424-SS; SOIC-14_3.9x8.7mm_P1.27mm

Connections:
+5V: J11.1, J11.2, J11.3, Q2.2 (D)
Blue: J1.4, Q1.3 (D)
GND: C1.1, C2.1, J1.6, J11.10, J11.11, J11.12, J14.5, J14.6, J14.7, J14.8, JP1.2 (B), Q1.2 (S), Q3.2 (S), Q4.2 (S), Q5.2 (S), Q6.2 (S), R5.1, U1.14 (GND)
Green: J1.3, J11.8
unnamed: J11.5, Q3.3 (D)
unnamed: J11.6, Q5.1 (G)
unnamed: J11.9, Q6.1 (G)
unnamed: JP1.1 (A), R3.1, U1.13 (PA3)
unnamed: Q1.1 (G), R1.1, U1.11 (PA1)
unnamed: Q2.1 (G), R2.2, U1.12 (PA2)
unnamed: Q3.1 (G), Q4.3 (D), R4.1
Pulse: Q6.3 (D), R7.1, U1.7 (PB2)
Pwr_mon: Q5.3 (D), R6.1, U1.8 (PB1)
Pwr_off: Q4.1 (G), R5.2, U1.9 (PB0)
Red: J1.2, J11.7
Signal: J1.5, R8.2, U1.2 (PA4)
UPDI: J11.4, U1.10 (~RESET/PA0)
VCC: F1.1, J14.1, J14.2, J14.3, J14.4, Q2.3 (S), R2.1
VCC_: C1.2, C2.2, F1.2, J1.1, R1.2, R3.2, R4.2, R6.2, R7.2, R8.1, U1.1 (VCC)

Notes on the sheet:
Alimentation 5v Alimente le RPI
Alimentation 5v Provien du module DC-DC

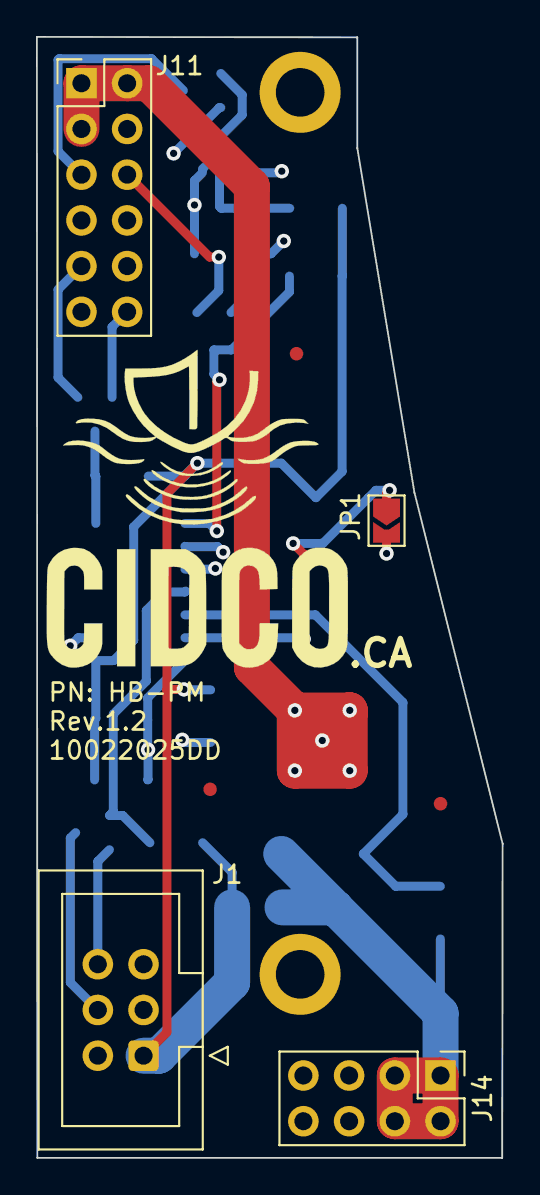
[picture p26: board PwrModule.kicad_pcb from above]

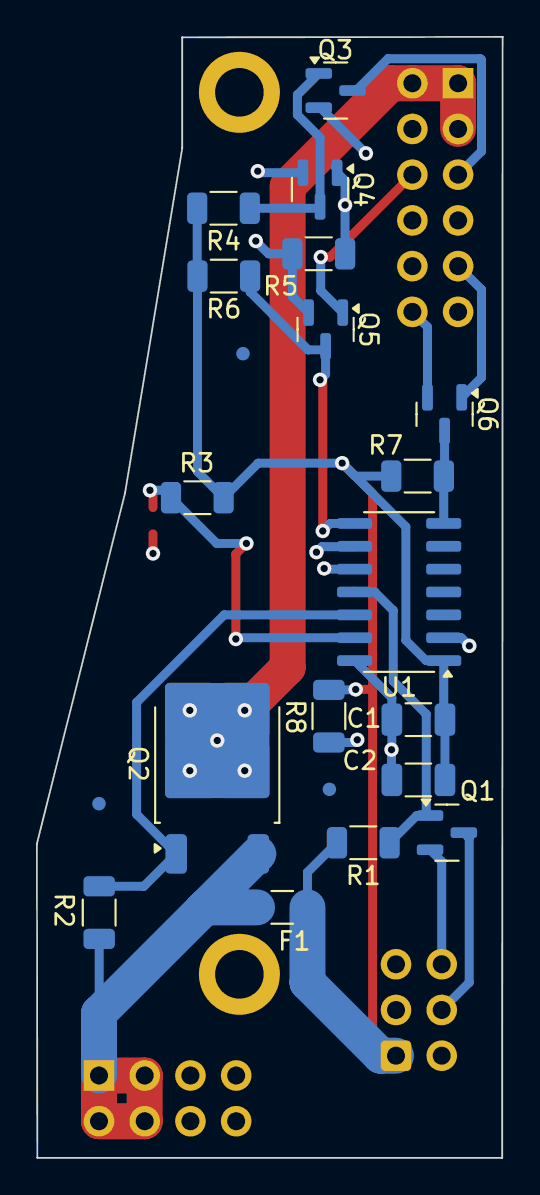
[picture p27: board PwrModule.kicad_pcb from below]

Board: 4 copper layers, 25.9 x 62.3 mm, 31 parts (21 on the bottom side), 19 nets.

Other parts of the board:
logo1: LOGO; logo cidco

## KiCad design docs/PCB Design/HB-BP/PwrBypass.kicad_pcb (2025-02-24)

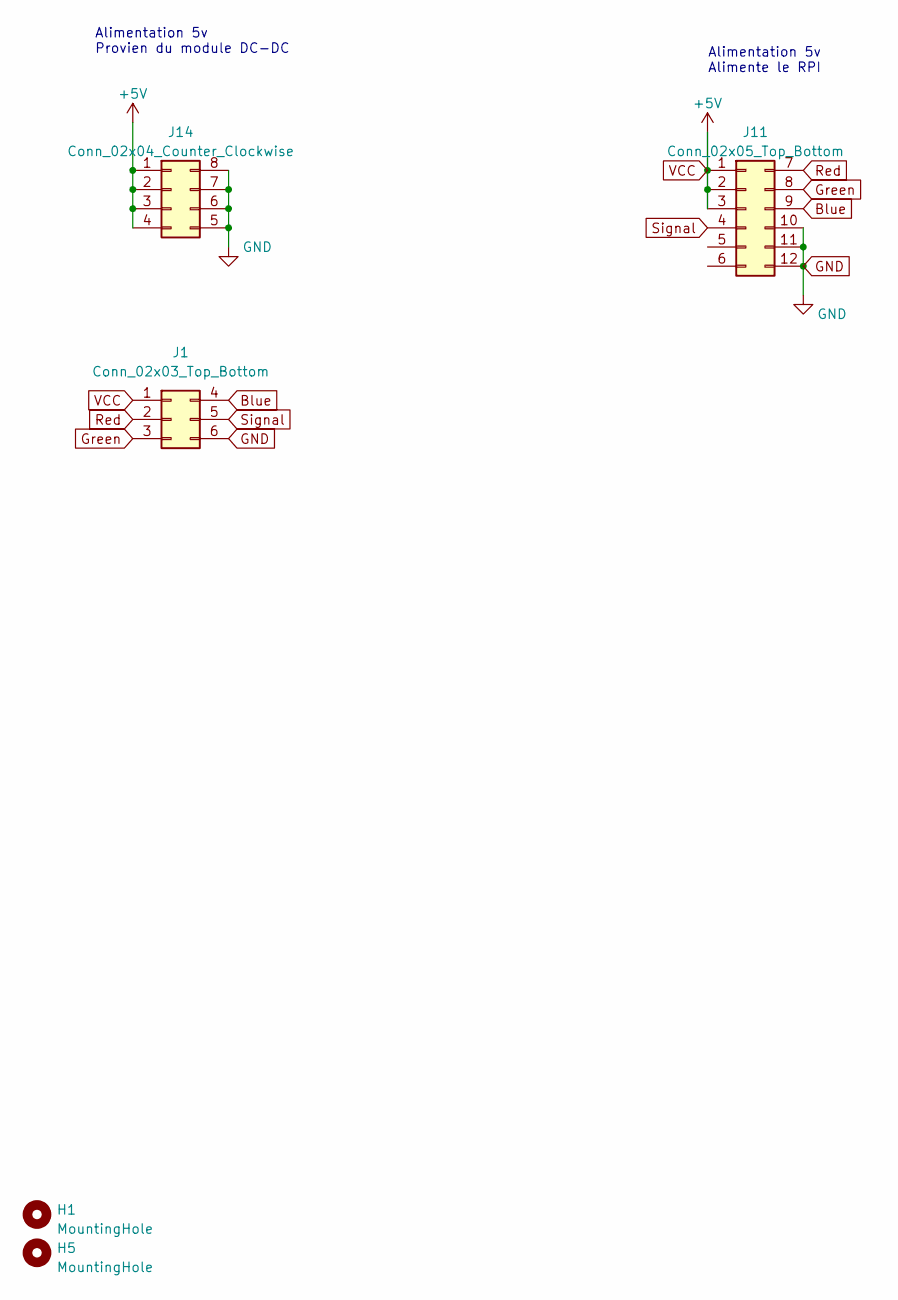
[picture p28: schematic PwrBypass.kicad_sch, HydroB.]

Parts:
H1, H5: MountingHole; MountingHole_2.7mm_M2.5_ISO7380_Pad
J1: Conn_02x03_Top_Bottom; IDC-Header_2x03_P2.54mm_Vertical
J11: Conn_02x05_Top_Bottom; PinHeader_2x06_P2.54mm_Vertical
J14: Conn_02x04_Counter_Clockwise; PinHeader_2x04_P2.54mm_Vertical

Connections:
Blue: J1.4, J11.9
GND: J1.6, J11.10, J11.11, J11.12, J14.5, J14.6, J14.7, J14.8
Green: J1.3, J11.8
Red: J1.2, J11.7
Signal: J1.5, J11.4
VCC: J1.1, J11.1, J11.2, J11.3, J14.1, J14.2, J14.3, J14.4

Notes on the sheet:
Alimentation 5v Alimente le RPI
Alimentation 5v Provien du module DC-DC

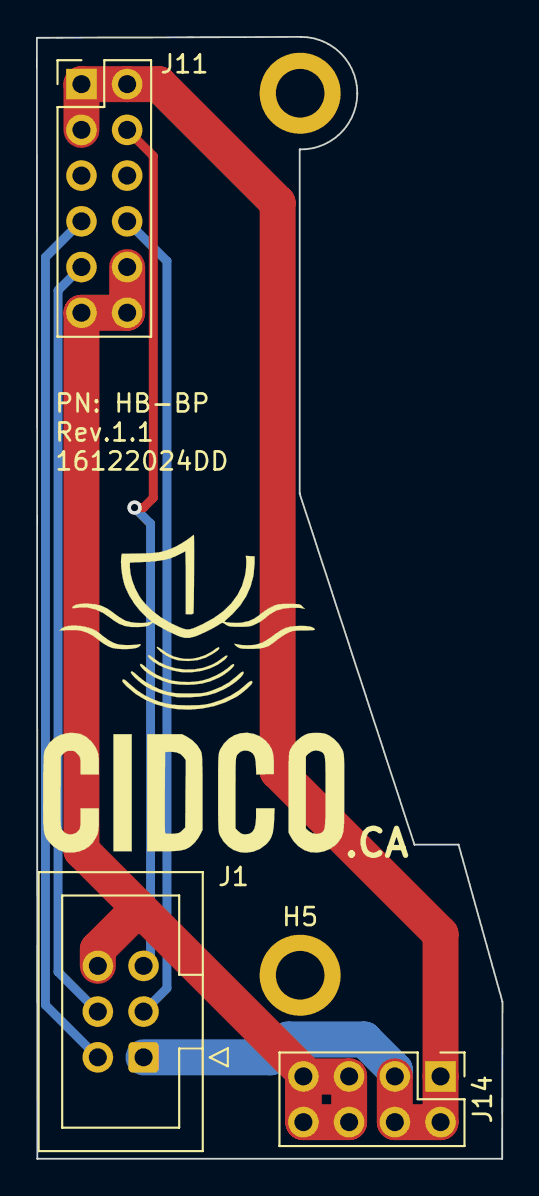
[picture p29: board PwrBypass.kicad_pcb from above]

Board: 2 copper layers, 25.9 x 62.3 mm, 6 parts (0 on the bottom side), 6 nets.

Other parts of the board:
logo1: LOGO; logo cidco

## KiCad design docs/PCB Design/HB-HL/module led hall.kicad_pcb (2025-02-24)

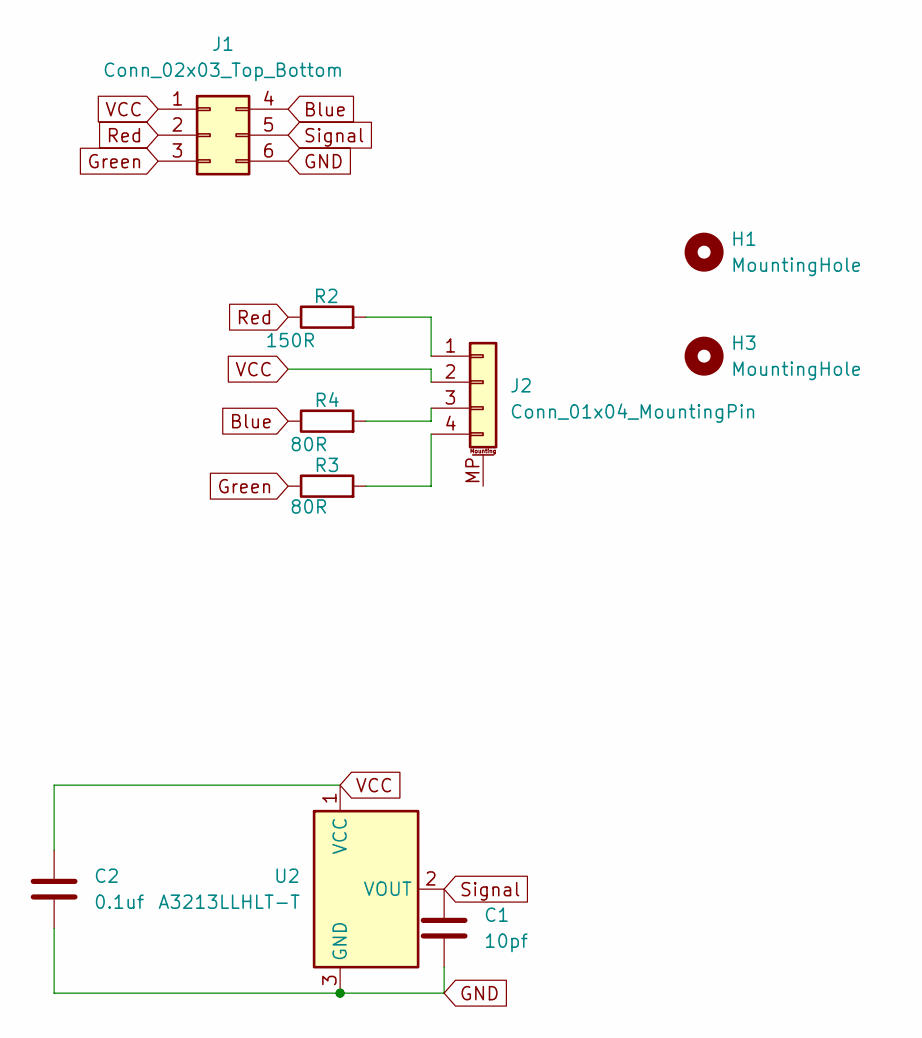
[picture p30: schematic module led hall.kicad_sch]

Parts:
C1: 10pf; C_1206_3216Metric
C2: 0.1uf; C_1206_3216Metric
H1, H3: MountingHole; MountingHole_4.3mm_M4
J1: Conn_02x03_Top_Bottom; IDC-Header_2x03_P2.54mm_Vertical
J2: Conn_01x04_MountingPin; TE_84952-4_1x04-1MP_P1.0mm_Horizontal
R2: 150R; R_1206_3216Metric
R3, R4: 80R; R_1206_3216Metric
U2: A3213LLHLT-T; SOT-23W

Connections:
Blue: J1.4, R4.1
GND: C1.2, C2.2, J1.6, U2.3 (GND)
Green: J1.3, R3.1
unnamed: J2.1, R2.2
unnamed: J2.3, R4.2
unnamed: J2.4, R3.2
Red: J1.2, R2.1
Signal: C1.1, J1.5, U2.2 (VOUT)
VCC: C2.1, J1.1, J2.2, U2.1 (VCC)

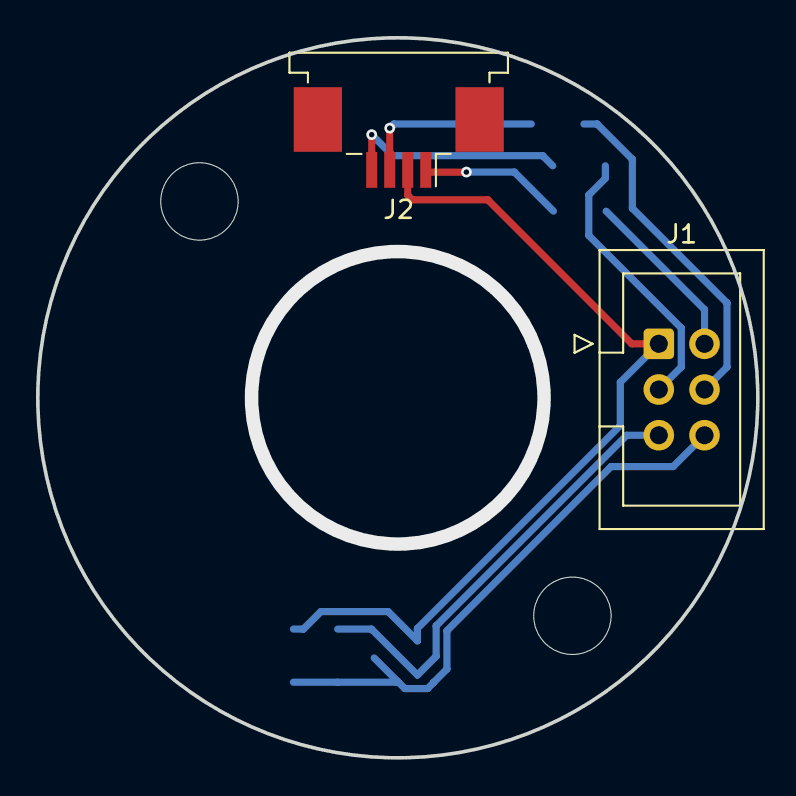
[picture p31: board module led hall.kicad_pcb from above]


Board: 2 copper layers, 40.0 x 40.0 mm, 10 parts (6 on the bottom side), 9 nets.

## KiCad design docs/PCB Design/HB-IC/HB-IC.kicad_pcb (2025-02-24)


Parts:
J1: 8P8C_Shielded; RJ45_HALO_HFJ11-x2450HRL_Horizontal
J2: Barrel_Jack_Switch; BarrelJack_Kycon_KLDX-0202-xC_Horizontal
J3: Conn_01x02_Pin; PhoenixContact_MSTBVA_2,5_2-G-5,08_1x02_P5.08mm_Vertical
J4: Conn_01x02_Pin
J5: Conn_01x08_Pin; PhoenixContact_MSTBVA_2,5_8-G-5,08_1x08_P5.08mm_Vertical

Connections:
GND: J2.2, J3.2, J4.2, J5.1, J5.4
RX+: J1.3, J5.6
RX-: J1.6, J5.5
TX+: J1.1, J5.8
TX-: J1.2, J5.7
V+: J3.1, J5.3
V-Bat: J2.1, J4.1, J5.2


Board: 2 copper layers, 97.8 x 77.9 mm, 6 parts (0 on the bottom side), 7 nets.

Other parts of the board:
logo1: LOGO; logo cidco

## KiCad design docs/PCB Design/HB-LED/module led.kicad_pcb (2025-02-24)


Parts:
D1: LED_ABGR; LED_D5.0mm-4_RGB
H1, H3: MountingHole; MountingHole_4.3mm_M4
J2: Conn_01x04_MountingPin; TE_84952-4_1x04-1MP_P1.0mm_Horizontal

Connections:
unnamed: D1.1 (A), J2.4
unnamed: D1.2 (BK), J2.3
unnamed: D1.3 (GK), J2.2
unnamed: D1.4 (RK), J2.1

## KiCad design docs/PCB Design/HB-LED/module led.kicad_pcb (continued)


Board: 2 copper layers, 21.5 x 31.2 mm, 5 parts (1 on the bottom side), 4 nets.

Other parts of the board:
logo1: LOGO; logo cidco

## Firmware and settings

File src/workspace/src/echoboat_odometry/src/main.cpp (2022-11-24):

#include <ros/ros.h>
#include <tf2_ros/transform_broadcaster.h>
#include <nav_msgs/Odometry.h>
#include <sensor_msgs/NavSatFix.h>
#include <sensor_msgs/Imu.h>
#include <sensor_msgs/PointCloud2.h>
#include <geometry_msgs/PointStamped.h>
#include <Eigen/Dense>

//TODO: this might be better off in a util class / module

#define D2R(x) ((M_PI*x)/180.0)

void geo2ecef(Eigen::Vector3d & positionECEF, double latitude, double longitude, double ellipsoidalHeight) {
	/**WGS84 ellipsoid semi-major axis*/
	double a = 6378137.0;

	/**WGS84 ellipsoid first eccentricity squared*/
	double e2 = 0.081819190842622 * 0.081819190842622;

	double slat = sin(D2R(latitude));
	double clat = cos(D2R(latitude));
	double slon = sin(D2R(longitude));
	double clon = cos(D2R(longitude));

	double N = a / (sqrt(1 - e2 * slat * slat));
	double xTRF = (N + ellipsoidalHeight) * clat * clon;
	double yTRF = (N + ellipsoidalHeight) * clat * slon;
	double zTRF = (N * (1 - e2) + ellipsoidalHeight) * slat;

	positionECEF << xTRF, yTRF, zTRF;
};

class GeoreferenceProvider{
public:
	GeoreferenceProvider(): ecefLocalOrigin(0,0,0){
	
	odomPublisher=n.advertise<nav_msgs::Odometry>("odom", 50);

	depthRepublisher = n.advertise<geometry_msgs::PointStamped>("depth_ned",50);

	gpsSubscriber = n.subscribe("fix", 50, &GeoreferenceProvider::processGpsCallback,this);
	//attitudeSubscriber = n.subscribe("/imu/pos_ecef", 50, &GeoreferenceProvider::processPositionCallback,this);
	attitudeSubscriber = n.subscribe("/imu/data", 50, &GeoreferenceProvider::processAttitudeCallback,this);
	lidarSubscriber = n.subscribe("/velodyne_points",100,&GeoreferenceProvider::processLidarCallback,this);
	depthSubscriber = n.subscribe("/depth",100,&GeoreferenceProvider::processDepthCallback,this);

	}

	void processGpsCallback(const sensor_msgs::NavSatFix & msg){

		//Init ENU frame origin once we receive a first fix
		if(!gpsFixObtained && msg.status.status >= 0){
			gpsFixObtained = true;
			latitudeLocalOrigin = msg.latitude;
			longitudeLocalOrigin = msg.longitude;
			altitudeLocalOrigin = msg.altitude;

			ROS_INFO("GPS Fix obtained. Initializing NED transform at (%f,%f,%f)",latitudeLocalOrigin,longitudeLocalOrigin,altitudeLocalOrigin);

			geo2ecef(ecefLocalOrigin,latitudeLocalOrigin,longitudeLocalOrigin,altitudeLocalOrigin);

			ROS_INFO_STREAM("Local Origin:" << ecefLocalOrigin);

			//ENU
			//ecef2local << 	-sin(D2R(longitudeLocalOrigin)),	cos(D2R(longitudeLocalOrigin)),	0,
			//		-sin(D2R(latitudeLocalOrigin))*cos(D2R(longitudeLocalOrigin)), -sin(D2R(latitudeLocalOrigin))*sin(D2R(longitudeLocalOrigin)), cos(D2R(latitudeLocalOrigin)),
			//		cos(D2R(latitudeLocalOrigin))*cos(D2R(longitudeLocalOrigin)),cos(D2R(latitudeLocalOrigin))*sin(D2R(longitudeLocalOrigin)),sin(D2R(latitudeLocalOrigin));

			//NED
			ecef2local <<-sin(D2R(latitudeLocalOrigin))*cos(D2R(longitudeLocalOrigin)),-sin(D2R(latitudeLocalOrigin))*sin(D2R(longitudeLocalOrigin)),cos(D2R(latitudeLocalOrigin)),
				   			-sin(D2R(longitudeLocalOrigin)) , cos(D2R(longitudeLocalOrigin)), 0,
							-cos(D2R(latitudeLocalOrigin))*cos(D2R(longitudeLocalOrigin)), -cos(D2R(latitudeLocalOrigin))*sin(D2R(longitudeLocalOrigin)), -sin(D2R(latitudeLocalOrigin)) ;

			//ROS_INFO_STREAM("DCM:" << ecef2local);
		}
		else if(gpsFixObtained){
			processPosition(msg);
		}
	}

	void processAttitudeCallback(const sensor_msgs::Imu & msg){
		lastAttitude = msg;
	}

	void processLidarCallback(const sensor_msgs::PointCloud2 & msg){
		//std::cout << "Got lidar data" << std::endl;
	}

	void processDepthCallback(const geometry_msgs::PointStamped & msg){
		//FIXME: this is solved in the imagenex driver but not in the rosbag so we need to republish to NED frame
		geometry_msgs::PointStamped newMsg = msg;
		newMsg.point.z=-1 * msg.point.z;
		depthRepublisher.publish(newMsg);		
	}

	/* Publish the odometry transform and Odometry message */
	void publishOdometry(Eigen::Vector3d & prpPointLocal){

		/* Broadcast the base_link to map transform */
        geometry_msgs::TransformStamped map_transform;
        map_transform.header.stamp = ros::Time::now(); //msg.header.stamp;
        map_transform.header.frame_id = "map"; //FIXME: we are assuming that the prp is the base_link origin
        map_transform.child_frame_id = "base_link";

        map_transform.transform.translation.x = prpPointLocal[0];
        map_transform.transform.translation.y = prpPointLocal[1];
        map_transform.transform.translation.z = prpPointLocal[2];
        map_transform.transform.rotation = lastAttitude.orientation;

        transformBroadcaster.sendTransform(map_transform);

        /* Publish the odometry message over ROS */
        nav_msgs::Odometry odom;
        odom.header.stamp = ros::Time::now();//msg.header.stamp;
        odom.header.frame_id = "odom";

        //set the position
        odom.pose.pose.position.x = prpPointLocal[0];
        odom.pose.pose.position.y = prpPointLocal[1];
        odom.pose.pose.position.z = prpPointLocal[2];

		//TODO: compensate attitude value using delta t, since our last attitude value dates from a little while back
        odom.pose.pose.orientation = lastAttitude.orientation;

        //set the velocity
        odom.child_frame_id = "base_link";
        //odom.twist.twist.linear.x = vx;
        //odom.twist.twist.linear.y = vy;
        //odom.twist.twist.angular.z = vth;

        //publish the message
        odomPublisher.publish(odom);
	}

	void processPosition(const sensor_msgs::NavSatFix & msg){
		if(gpsFixObtained){
			lastPosition = msg;

			//transform to ENU
			Eigen::Vector3d pointEcef;

			geo2ecef(pointEcef,msg.latitude,msg.longitude,msg.altitude);

			Eigen::Vector3d pointLocal = ecef2local * (pointEcef - ecefLocalOrigin);

			//Update odometry
			publishOdometry(pointLocal);
		}
	}



	void run(){
		ros::Rate r(10.0);

		//just spin...
		while(n.ok()){
			ros::spinOnce();
			r.sleep();
		}
	}

private:
	ros::NodeHandle n;
	ros::Publisher  odomPublisher;

	ros::Publisher  depthRepublisher;//FIXME: delete this

	ros::Subscriber gpsSubscriber;

	ros::Subscriber positionSubscriber;
	ros::Subscriber attitudeSubscriber;
	ros::Subscriber lidarSubscriber;
	ros::Subscriber depthSubscriber;



	tf2_ros::TransformBroadcaster transformBroadcaster;

	//These are used to georeference
	sensor_msgs::Imu 	lastAttitude;
	sensor_msgs::NavSatFix  lastPosition;

	bool gpsFixObtained = false;

	//This DCM is used to transform ECEF coordinates into a local NED frame centered at ecefEnuOrigin
	Eigen::Matrix3d	ecef2local;

	//The NED origin is set as the first position when a proper GPS fix is obtained
	Eigen::Vector3d ecefLocalOrigin;

	//NED origin in geodesic coordinates
	double latitudeLocalOrigin;
	double longitudeLocalOrigin;
	double altitudeLocalOrigin;
};

int main(int argc, char** argv){
  ros::init(argc, argv, "odometry_publisher");

  GeoreferenceProvider georefProvider;

  georefProvider.run();
}

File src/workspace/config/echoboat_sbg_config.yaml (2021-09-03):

# Configuration file for SBG device through an Udp interface.

# Configuration of the device with ROS.
confWithRos: false

# Udp configuration
ipConf:
  ipAddress: "10.0.0.2"              # Ip address of the device.
  out_port: 1234                    # Output port of the device.
  in_port: 5678                     # Inport of the device.

# Sensor Parameters
sensorParameters:
  # Initial latitude (°)
  initLat: 48.419727
  # Initial longitude (°)
  initLong: -4.472119
  # Initial altitude (above WGS84 ellipsoid) (m)
  initAlt: 100.0
  # Year at startup
  year: 2018
  # month in year at startup
  month: 03
  # day in month at startup
  day: 10

  # Montion profile ID
  # 1 GENERAL_PURPOSE Should be used as a default when other profiles do not apply
  # 2 AUTOMOTIVE      Dedicated to car applications
  # 3 MARINE          Used in marine and underwater applications
  # 4 AIRPLANE        For fixed wings aircraft
  # 5 HELICOPTER      For rotary wing aircraft
  motionProfile: 3

# IMU_ALIGNMENT_LEVER_ARM
imuAlignementLeverArm:
  # IMU X axis direction in vehicle frame
  # 0 ALIGNMENT_FORWARD   IMU Axis is turned in vehicle's forward direction
  # 1 ALIGNMENT_BACKWARD  IMU Axis is turned in vehicle's backward direction
  # 2 ALIGNMENT_LEFT      IMU Axis is turned in vehicle's left direction
  # 3 ALIGNMENT_RIGHT     IMU Axis is turned in vehicle's right direction
  # 4 ALIGNMENT_UP        IMU Axis is turned in vehicle's up direction
  # 5 ALIGNMENT_DOWN      IMU Axis is turned in vehicle's down direction
  axisDirectionX: 0
  # IMU Y axis direction in vehicle frame
  # 0 ALIGNMENT_FORWARD   IMU Axis is turned in vehicle's forward direction
  # 1 ALIGNMENT_BACKWARD  IMU Axis is turned in vehicle's backward direction
  # 2 ALIGNMENT_LEFT      IMU Axis is turned in vehicle's left direction
  # 3 ALIGNMENT_RIGHT     IMU Axis is turned in vehicle's right direction
  # 4 ALIGNMENT_UP        IMU Axis is turned in vehicle's up direction
  # 5 ALIGNMENT_DOWN      IMU Axis is turned in vehicle's down direction
  axisDirectionY: 3
  # Residual roll error after axis alignment rad
  misRoll: 0
  # Residual pitch error after axis alignment rad
  misPitch: 0
  # Residual yaw error after axis alignment rad
  misYaw: 0
  # X Primary lever arm in IMU X axis (once IMU alignment is applied) m
  leverArmX: 0
  # Y Primary lever arm in IMU Y axis (once IMU alignment is applied) m
  leverArmY: 0
  # Z Primary lever arm in IMU Z axis (once IMU alignment is applied) m
  leverArmZ: 0

# AIDING_ASSIGNMENT
# Note: GNSS1 module configuration can only be set to an external port on Ellipse-E version.
# Ellipse-N users must set this module to MODULE_INTERNAL. On the other hand, rtcmModule is only
# available for Ellipse-N users. This module must be set to MODULE_DISABLED for other users.
aidingAssignment:
  # GNSS module port assignment:
  # 255 Module is disabled
  # 1 Module connected on PORT_B
  # 2 Module connected on PORT_C
  # 3 Module connected on PORT_D
  # 5 Module is connected internally
  gnss1ModulePortAssignment: 255
  # GNSS module sync assignment:
  # 0 Module is disabled
  # 1 Synchronization is done using SYNC_IN_A pin
  # 2 Synchronization is done using SYNC_IN_B pin
  # 3 Synchronization is done using SYNC_IN_C pin
  # 4 Synchronization is done using SYNC_IN_D pin
  # 5 Synchronization is internal
  # 6 Synchronization is done using SYNC_OUT_A pin
  # 7 Synchronization is done using SYNC_OUT_B pin
  gnss1ModuleSyncAssignment: 0
  # RTCM input port assignment for Ellipse-N DGPS
  rtcmPortAssignment: 255
  # Odometer module pin assignment
  # 0 Odometer is disabled
  # 1 Odometer connected only to ODO_A (unidirectional).
  # 2 Odometer connected to both ODO_A (signal A) and ODO_B (Signal B or direction) for bidirectional odometer.
  odometerPinAssignment: 0
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

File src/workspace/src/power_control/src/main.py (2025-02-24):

#!/usr/bin/env python3
import rospy
import RPi.GPIO as GPIO
import subprocess
import time
from std_msgs.msg import String  # To receive LED control commands

# GPIO numbers (BCM mode)
GPIO_OUT = 16   # Pin set to HIGH on startup
GPIO_IN  = 22   # Pin monitored for shutdown
GPIO_Pulse = 23 # Pin for pulse signal

GPIO_RED = 26   # Red LED
GPIO_GREEN = 27 # Green LED

# Initialize global variables for LED control
blinking = False
led_state = "off"
debug_mode = False  # Set to 'False' to disable debug warnings

def shutdown_callback():
    """ Callback triggered when GPIO_IN detects a rising edge, shutting down the Raspberry Pi. """
    if debug_mode:
        rospy.logwarn(f"⚠️ GPIO {GPIO_IN} detected: Initiating shutdown...")
    subprocess.call(["shutdown", "now"])

def on_shutdown():
    """ Function executed when ROS shuts down the node. It turns off all LEDs before exiting. """
    if debug_mode:
        rospy.logwarn("⚠️ Node is shutting down. Turning off all LEDs.")
    GPIO.output(GPIO_OUT, GPIO.LOW)
    GPIO.output(GPIO_RED, GPIO.LOW)
    GPIO.output(GPIO_GREEN, GPIO.LOW)
    #GPIO.cleanup()

def set_led_state(state):
    """ Turns LEDs on/off based on the given state """
    global blinking, led_state  # Use global variables
    led_state = state
    blinking = False

    if debug_mode:
        rospy.logwarn(f"🔆 LED State Change: {state}")

    if state == "off":
        GPIO.output(GPIO_RED, GPIO.LOW)
        GPIO.output(GPIO_GREEN, GPIO.LOW)
        if debug_mode:
            rospy.logwarn("🟡 LEDs OFF")
    elif state == "ready":
        GPIO.output(GPIO_RED, GPIO.LOW)
        GPIO.output(GPIO_GREEN, GPIO.HIGH)
        if debug_mode:
            rospy.logwarn("🟢 READY: Green LED ON")
    elif state == "recording":
        blinking = True  # Green LED blinking at 1Hz
        if debug_mode:
            rospy.logwarn("🟢 RECORDING: Green LED will blink")
    elif state == "warning":
        GPIO.output(GPIO_RED, GPIO.HIGH)
        GPIO.output(GPIO_GREEN, GPIO.HIGH)
        if debug_mode:
            rospy.logwarn("🟡 WARNING: Both LEDs ON")
    elif state == "error":
        GPIO.output(GPIO_RED, GPIO.HIGH)
        GPIO.output(GPIO_GREEN, GPIO.LOW)
        if debug_mode:
            rospy.logwarn("🔴 ERROR: Red LED ON")
    elif state == "nofix":
        blinking = True  # Both LEDs blinking at 1Hz
        if debug_mode:
            rospy.logwarn("🟡 NOFIX: Both LEDs will blink")
    else:
        if debug_mode:
            rospy.logwarn(f"❌ Invalid LED state received: {state}")

def led_control_callback(msg):
    """ ROS callback to update LED state based on received message """
    if debug_mode:
        rospy.logwarn(f"📩 Received LED state: {msg.data}")
    set_led_state(msg.data)

def main():
    """ Main ROS loop """
    rospy.init_node('gpio_control_node', anonymous=True)

    if debug_mode:
        rospy.logwarn("🚀 Starting GPIO Control Node...")
    
    rospy.on_shutdown(on_shutdown)

    # Subscribe to the topic to receive LED state commands
    rospy.Subscriber("led_control", String, led_control_callback)

    # Initialize GPIO
    try:
        GPIO.setwarnings(False)
        GPIO.cleanup()
        
        GPIO.setmode(GPIO.BCM)
        GPIO.setup(GPIO_OUT, GPIO.OUT)
        GPIO.output(GPIO_OUT, GPIO.HIGH)

        GPIO.setup(GPIO_IN, GPIO.IN, pull_up_down=GPIO.PUD_UP)
        GPIO.add_event_detect(GPIO_IN, GPIO.FALLING, callback=lambda _: shutdown_callback(), bouncetime=300)

        GPIO.setup(GPIO_Pulse, GPIO.OUT)
        GPIO.setup(GPIO_RED, GPIO.OUT)
        GPIO.setup(GPIO_GREEN, GPIO.OUT)
        GPIO.output(GPIO_RED, GPIO.LOW)
        GPIO.output(GPIO_GREEN, GPIO.LOW)
        GPIO.setwarnings(True)
        if debug_mode:
            rospy.logwarn("✅ GPIO Initialization Successful!")

    except Exception as e:
        if debug_mode:
            rospy.logwarn(f"❌ GPIO Initialization Failed: {e}")
        return

    rate = rospy.Rate(1)  # 1Hz frequency for blinking LEDs
    pulse = False

    while not rospy.is_shutdown():
        pulse = not pulse
        GPIO.output(GPIO_Pulse, pulse)

        # Handle blinking LED states
        if blinking:
            if led_state == "recording":
                GPIO.output(GPIO_RED, GPIO.LOW)
                GPIO.output(GPIO_GREEN, not GPIO.input(GPIO_GREEN))  # Green blinking
                if debug_mode:
                    rospy.logwarn("🟢 RECORDING: Green LED Blinking")
            elif led_state == "nofix":
                GPIO.output(GPIO_RED, not GPIO.input(GPIO_RED))  # Red blinking
                GPIO.output(GPIO_GREEN, not GPIO.input(GPIO_GREEN))  # Green blinking
                if debug_mode:
                    rospy.logwarn("🟡 NOFIX: Both LEDs Blinking")

        rate.sleep()

if __name__ == "__main__":
    main()

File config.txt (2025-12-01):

apiKey SECRET
apiPort 8080
apiServer localhost
apiUrlPath /
geofence MULTIPOLYGON(((-180 -90, -180 90, 180 90, 180 -90, -180 -90)))
headingOffset 0.020331
hotspotSSID DOMINIC-240787-007
logRotationIntervalSeconds 3600
loggingMode 2
pitchOffset -1.447684
rollOffset 1.609092
sonarAbsorbtion 20
sonarPulseLength 120
sonarRange 20
sonarSerialBaudRate 9600
sonarStartGain 16
speedThresholdKmh 6.0
wifiPassword qwerty1234
wifiSSID cidco
wifiTransferEnabled true

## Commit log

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2020-01-21 Fix JSON + debut state_controller
    [main.cpp]
2020-01-30 Add Hardware
    Add hardware files
    [BOM HAT.ods, BOM HAT.xls, BOM PSU light.xls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]
2020-02-03 Device init fix;Web UI fixes
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2020-02-19 mise a jours du fichier pcb pour l'alimentation pour que le rpi soit installer dessu avec des standoff pour permetre d'integrer le tout dans le catarob
    [psu-pcb-B_Cu.gbl, psu-pcb-B_Mask.gbs, psu-pcb-B_Paste.gbp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]
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2020-03-04 ajout du module pour le zed-f9p en préléminaire
    [ubx_config.txt]
2020-03-04 enregistrement d'un ficiher avec le caractere 1 en fonction de la date et de l'heure de lordinateur il existe un petit probleme pour transferer le path dans le process
    [main.cpp]
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2020-03-06 Testing reset of currentGoal
    [main.cpp]
2020-03-06 Moved 'currentGoal.reset();' to constructor
    [main.cpp]
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2020-03-16 derniere version du catarob control suivit du loger pour le gps sed et la configuration du zed. la partie de configuration du zed fonctionne par internitence a valider.
    [ubx_config.txt]
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2020-03-17 correction de la structure des donnée envoyer au serveur websocket
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2020-03-23 séparation du websocket pour control websocket et goal websocket et mise a jours du site web
    [BOM PSU light.xls]
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2020-03-24 correction gelage du navigateur apret 45 minnute lors de l'observation des donée
2020-03-25 ajout de inertialsence ros module. correction site web. correction websocket catarob pour éviter l'envois de mauvaise donée.
    [inertial_sense.h, main.cpp]
2020-03-25 correction pour la mise a jours du tracé sur supression d'une position dans la page web du goal planner
2020-04-02 correction du module pour l'ins inertial sense et ajout du module de test catch-ros et premier test pour dummy gnss
    [inertial_sense.h, main.cpp]
2020-04-07 ajout de la fonction test dans gnss_dummy
    [BOM PSU.csv, RPi_GPIO.sch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]
2020-04-07 Revert "ajout de la fonction test dans gnss_dummy"
    This reverts commit 1c5e7aea82a86bf98b11077181f012bde75526f7.
    [BOM PSU.csv, RPi_GPIO.sch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]
2020-04-07 Revert "correction du module pour l'ins inertial sense et ajout du module de test catch-ros et premier test pour dummy gnss"
    This reverts commit efa8cc41cf06bfaf70945a43878b15c1b2e144ff.
    [inertial_sense.h, main.cpp]
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2020-04-17 mise a jours des diferent node pour suporter les test de gtest. les test ne sont pas tous implementer presentement. il y a 4 node ui ne compile pas et cest relier au message qui as ete generer soit c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
    [ubx_config.txt]
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2020-05-21 Update 2-network.sh
    correction pour la gestion du nouveau site web
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2020-05-21 Update 2-network.sh
    correction de la gestion de l'addresse ip a la place d'utiliser la mac adresse comme identifieur de l'interface on utilise le nom
    correction de la commande pour relancer lighttpd de reload a restart
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2020-05-22 mise a jours des fichier mise a jours de mon cote et celui de l'avancement de poseidon
    [BOM PSU.csv, DB-5R5D105T.stl, DB-5R5D105T.stp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]
2020-05-22 correction de catarob control pour utiliser la nouvelle structure de repertoire pour wiringpi
2020-05-22 correction pour l<utilisation du bon d/pot pour wiringpi
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2020-06-12 version préléminaire du websocket pour la config. Version finale de la page web pour la config. La page permet d'afficher la liste de configuration provenant du websocket et permet d'envoyer la versi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
2020-06-15 websocket fonctionnel en bi directionnel il reste a travailler la page web pour la gestion de l'affichage et optimiser la gestion de la réception et l'envois des donnée. On dois utiliser F5 pour rafr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
    [config.txt]
2020-06-15 correction de la page web
    [config.txt]
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2020-07-09 Update logger_text.cpp
    correction de la gestion du timestamp
2020-07-09 Update logger_binary.cpp
    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
2020-08-07 play launch file and play script sh
    [config.txt]
2020-08-07 Integrated BNO055 with Poseidon
    [config.txt]
2020-08-07 Fixed imu_bno055 driver to use ENU convention
    [bno055_i2c_activity.cpp]
2020-08-08 Fix calibration service
    [config.txt]
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2020-08-17 Ajout config + launch file hbox
    [config.txt]
2020-08-19 added configuration service to sonar_dummy
    [config.txt]
2020-08-21 Fixed logger_text
    [config.txt]
2020-09-03 Update status.html
    correction de l'affichage du status de poseidon
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2020-09-25 Added IMU zero functionality
    [config.txt]
2020-09-25 Fixed D2R error and config persistence for IMU offsets
2020-09-30 Ajouts transformations IMU->Body & demarrage du logging
    [config.txt]
2020-10-06 tests now work with tf2 framework
    [config4Tests.txt]
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2020-10-07 moved config file for tests
    [config4Tests.txt]
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2020-10-20 Fixes quaternion utils
    [config.txt]
2020-10-21 Update config.txt
    put offset at 0 for the imu
    [config.txt]
2020-10-21 Moved quaternion utils to use tf2 instead
    [config.txt]
2020-10-21 Removed excessive logging from websocketpp
    [config.txt]
2020-10-21 Normalized headings between 0-360 in websocket telemetry output and inside logger_text
    [BOM HAT.ods, BOM HAT.xls, BOM PSU.csv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]
2020-10-22 fix in the data websocket the vital cpu temp form real to integer, fix the graphical element of cpu temperature in status.html
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2020-11-04 fix rosbag
    [config.txt]
2020-11-04 fix loger for the right topic of the imu ODOM to IMU/DATA
2020-11-04 fix i2c spped for imu #189
2020-11-10 imu_zero_offset, get_state and get_configuration tests
    [getConfigurationTestConfig.txt, zeroImuOffsetTestConfig.txt]
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2020-11-10 config.txt and launch file for data websocket test
    [config4Tests.txt]
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2020-12-08 fix imu bno055 remap and ccw to cw need to add mod on the ccw
    [config.txt]
2020-12-10 fix bno055 calib file generation
    [bno055_i2c_activity.cpp]
2021-03-11 Add files via upload
    add wiring diagram and block diagram
    [poseidon.kicad_pcb, poseidon.sch]
2021-03-11 update my branch and add diagram files
    [config4Tests.txt, getConfigurationTestConfig.txt, poseidon.kicad_pcb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]
2021-07-23 mavros added and echoboat launch script
    [schematic_plane.urdf.xacro, servo_state_publisher.yaml, uncrustify-cpp.cfg]
2021-09-02 fix the serial assignment for the sonar
2021-09-16 first draft of piksi integration, deleted mavros since it will become submodule
    [schematic_plane.urdf.xacro, servo_state_publisher.yaml, uncrustify-cpp.cfg]
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2021-11-08 Echoboat init & Hydroblock fix
    [echoboat.urdf, schematic_plane.urdf.xacro, servo_state_publisher.yaml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]
2021-11-08 Fix Imagenex PPS trigger
    [main.cpp]
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2021-11-09 fix dumies and add imu null
    [config4Tests.txt]
2021-11-10 Fix raspberry vital
2021-11-10 fix web interface and sonar nmea
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2021-11-25 resolving issue #251 start
    [config.txt]
2022-01-12 upgrade the kicad project from v4 to v6 correct the wiring diagram and update the file wiring diagram.pdf
    [poseidon.kicad_sch]
2022-01-12 update the docs directory
    [BOM HAT.ods, BOM HAT.xls, BOM PSU.csv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]
2022-01-13 mise a jour du diagram et renomer le fichier
    [poseidon.kicad_sch]
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2022-01-14 switch triggers script once fixed
2022-01-15 exchange switch for dropdown menu
    [config.txt]
2022-01-15 get & set logger mode service callback
    [config.txt]
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2022-01-20 uppdate DC to DC converter in the BOM
    [Poseidon Bom V1.0 en.xlsx, Poseidon Bom V1.0 fr.xlsx]
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2022-02-19 fix uart service
2022-02-25 checkpoint config websocket unittest
    [config.txt]
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2022-02-28 smalls fixs
    [zeroImuOffsetTestConfig.txt]
2022-03-11 Removed mavros source, and included it in the base install as a Ubuntu module instead
    [schematic_plane.urdf.xacro, servo_state_publisher.yaml, uncrustify-cpp.cfg]
2022-05-31 Fix the sonar speed in the uart service on boot
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2023-03-22 apiKey in config file
    [config.txt]
2023-03-22 api key in config + hdd logger notification
    [config.txt]
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2023-05-03 code cleaning + wifiTransferEnabled changes
    [config.txt]
2023-06-06 lidar timestamp fix
2023-07-31 bug fixes
    [config.txt]
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2023-09-19 gnss fix test + ui feedback and refresh buttons
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2023-09-22 ui fix + imu calibration test change
2023-09-27 imu calibration corner case fix
2023-09-29 imu calib fix
2023-09-29 added roll pitch heading in error message
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2023-09-29 imu calib diag fix
2023-10-05 fix bno055 calibration file location
    [bno055_i2c_calibration.cpp]
2023-10-06 fix imu offset to 0
    [config.txt]
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2023-11-09 convert neh imagenex node from c to py and add fixes
    [main.cpp, main.py]
2023-11-09 fix timestamp in sonar imagenex852 py
    [main.py]
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2023-11-10 add missing code comment c++ code
    [main.py]
2023-11-10 fix sonar command value
    [main.py]
2023-11-10 fix configuration change function
    [main.py]
2023-11-10 rework of the sonar imagenex852 node
    Node is functional sending data on depth and depth ENU
    readinf configuration from topic populated by config websocket node
    need more tuning and test
    [main.py]
2023-11-10 Fix launch file for sonar imagenex node
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2023-11-13 remove python script and replace it by a bash script to fix the device name in the hotspot conneciton
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2023-12-12 Issue #350
    [config.txt]
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2024-02-22 Revert "serial baud rate"
    This reverts commit 8338fe8e467abb22f961f1f04ff004abcdcd0438.
    [config.txt]
2024-02-22 serial baud rate setting
    [config.txt]
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2024-02-28 fix port not getting set at launch
    serial baud rate functional
    serial baud rate functional
    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
    [config.txt]
2024-02-28 serial baud rate
    Revert "serial baud rate"
    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
    [config.txt]
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2024-05-07 Renaming out dated content
    [BOM HAT.ods, BOM HAT.xls, BOM PSU.csv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]
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2024-05-08 change hotspot ssid via ui
    [config.txt]
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2024-07-09 fix sonar initialisation and depth variable
    [main.py]
2024-07-09 fix sonar imaginex gain and absorbtion
    [main.py]
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2024-09-17 led error triggers
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2024-11-01 fix the file reading to be able to load the multi polygone
    [config.txt]
2024-11-01 fix geofence
    [config.txt]
2024-11-14 Revert "PR Geofence #398"
    [i2c_controller_node.cpp]
2024-11-18 Add fixes made by Patrick and add information hiden in the web page if the i1c sensor are not present
    [i2c_controller_node.cpp]
2024-11-18 fix i2c controller and fix launch files
2024-11-22 fixe web interface for missing sensors
2024-11-22 catch javascript error when the position filed from the web socket are empty #397
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2025-02-10 fix led state
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2025-02-11 fix battery voltage value
2025-02-11 fix error on sonar no value
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2025-02-11 HydroBlock Installation Manual and User Manual HydroBlock PCB Rev 1 Led Module PCB Rev 0
    [EDI2CAP.CFG, HV-5RGB60.SchLib, HV-5RGB60.stp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]
2025-02-11 Cleaning Out Dated PCB
    [BOM HAT.ods, BOM HAT.xls, BOM PSU.csv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]
2025-02-11 Hydroblock PCB Rev 0.2
    [hydroblock.kicad_pcb, hydroblock.kicad_sch]
2025-02-11 HydroB PCB Rev 0.3 Module bypass rev 1.0 Module power rev 1.0
    [HydroBall.kicad_pcb, HydroBall.kicad_sch, PwrBypass.kicad_pcb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]
2025-02-11 module power 1.0 module bypass 1.1
    [PwrBypass.kicad_pcb, PwrBypass.kicad_sch, PwrModule.kicad_pcb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]
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2025-02-11 led rev 1.0 hall rev 0.3 programmer interface 1.0
    [EDI2CAP.CFG, HV-5RGB60.SchLib, HV-5RGB60.stp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]
2025-02-11 Directory rename and readme updated
    [HydroBall.kicad_pcb, HydroBall.kicad_sch, PwrBypass.kicad_pcb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]
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2025-02-11 HB-HAT replace led driver by mosfet connected on GPIO
    [HydroBall.kicad_pcb]
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2025-02-12 fix nodes to control eht led with the GPIO
    [main.py]
2025-02-12 PCB : HB-HAT replace led driver by mosfet connected on gpio
    [HydroBall.kicad_pcb, HydroBall.kicad_sch]
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2025-02-19 Add interconnect PCB board
    [HB-IC-B_Cu.gbr, HB-IC-B_Mask.gbr, HB-IC-B_Paste.gbr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]
2025-02-27 update the power module programmer interface to be able to power the power module from a usb port if programmed with an atmel ice programmer
    [prog.kicad_pcb, prog.kicad_sch]
2025-02-27 DC to DC converter replacement with filtration and voltage correction TBC.
    [HydroBall.kicad_pcb, HydroBall.kicad_sch]
2025-02-27 PCB HB-HAT : fix mosfet pinout
    [HydroBall.kicad_pcb, HydroBall.kicad_sch]
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2025-03-05 no led at boot when we alredy have gps fix
2025-03-19 fix battery voltage treshold
2025-03-19 fix the color of the battery voltage in the system status webpage
2025-03-19 fix the system status when wen the battery is charging
2025-03-19 fix voltage bar on the system status web page
2025-03-19 fix battery voltage in normal state from 13.5v to 11.9v in rpi_vitals
2025-03-19 fix the battery voltage from 13.5 to 11.9v in the web interface
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2025-04-10 fix i2c4 configuration
2025-05-22 fix launch script with good I2C port and update node line and add wifi and diagnostics.
    fix wifi config node
2025-12-01 fix sonar node name
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2025-12-01 add ins_piksi in the blacklist and fix imu null test script
2025-12-01 blacklist imu_bno055 node and rpivitals fix launch file for the logger test
2025-12-01 fix pkg name for the test odf the sonar imaginex C
2025-12-01 fix sonar nmea0183 test
2025-12-01 fix logger test
    [getConfigurationTestConfig.txt]
2025-12-01 add dependencies and fix logger test
    [zeroImuOffsetTestConfig.txt]
2025-12-01 - Fixed logger text test build by defining `currentRssBytes` helper in `test_logger_text_node.cpp`.
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2025-12-01 - Logger tests: removed embedded PEM key/cert; tests now generate ephemeral self-signed TLS material at runtime to avoid shipping secrets. - sonar_nmea_0183_tcp_client: use ROS params for IP/port (in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
2025-12-01 raspberrypi_vitals: ensure targets depend on generated messages (catkin_EXPORTED_TARGETS) and declare i2c_controller_service in CATKIN_DEPENDS to fix missing `raspberrypi_vitals_msg/sysinfo.h` during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
2025-12-01 lidar_filtering: fixed tests by passing min/max angle/distance as const refs in Filters helpers (no more rvalue binding errors).
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2025-12-01 fix cmakelist for power manager and wifi file transter
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2025-12-01 fix name for sonar nmea
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2025-12-02 - install: rewrote `install/stages/ethernet_move_hotspot_rpi4.sh` with Unix line endings so the bash shebang runs without `/bin/bash^M` errors.
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2025-12-02 - wifi_file_transfer_config: protect hotspot/non-target interfaces (e.g., wlan1) and force new connections onto `wlan0`; skip deleting hotspot profiles when applying Wi‑Fi config. - wifi_file_transfe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
2025-12-18 - diagnostics/e2e: make IMU/sonar communication thresholds configurable via env vars (`POSEIDON_DIAG_IMU_*`, `POSEIDON_DIAG_SONAR_*`) to reduce false negatives on slower benches. - e2e: allow tuning 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
2025-12-18 - e2e: keep a DBT NMEA writer running for the whole E2E so `/depth` can be validated when `DIAGNOSTICS_FAKE_SERIAL_PORT` is available. - e2e: optional exclusive mode (`POSEIDON_E2E_EXCLUSIVE=1`) stop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
